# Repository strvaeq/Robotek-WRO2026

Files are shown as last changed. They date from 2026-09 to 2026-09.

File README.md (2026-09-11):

# Renkay - WRO 2026 Future EngineersrobotekPeru Flag

<p align="center">
  Banner Renkay
</p>





**Welcome! 🐨✨**

We are Renkay, a team of three students participating at the 2026 World Robot Olympiad! This GitHub repository contains the documentation, code, and full development journey of our autonomous vehicle, designed and built to compete in the Future Engineers Challenge.

<br>

> [!NOTE]
> 🤔 Why is our team named *Renkay*?<br><br>
> The name *Renkay* is inspired by three words that define our team: resilience, minka, and wiñay. "**Resilience**" represents our determination to never give up; "**minka**", an ancestral tradition of working together for a common purpose, reflects our belief that the best ideas are built through collaboration; and wiñay, which means "to grow", symbolizes our commitment to continuous learning and improvement. Together, these words represent who we are as a team, and guide every step of our robotics journey.

<br>

---

# 📮 Table of Contents
1. [About the Competition](about-the-competition)
   + [World Robot Olympiad (WRO)](world-robotic-olympiad-(wro))
   + [Future Engineers Category](future-engineers-category)
   + [Challenges Overview](challenges-overview)
2. [Repository Structure](repository-structure)
3. [Meet the Team!](meet-the-team)
4. [Vehicle Overview](vehicle-overview)
   + [General Description of the Car](#general-description-of-the-car)
   + [Versions of the Car](#versions-of-the-car)
     
5. [System Setup](system-setup)
   + [Operating Environment Overview](#operating-environment-overview)
   + [Robot Operating System (ROS)](#robot-operating-system-ros-)
   + [Ubuntu](#ubuntu-)
   + [Raspberry Pi](#raspberry-pi-)
     
6. [Mobility Management](mobility-management)
   + [Steering System - Ackermann](#steering-system--ackermann)
   + [Motor and Drivetrain](#motor-and-drivetrain)
   + [3D Pieces](#3d-pieces)
   
7. [Power & Sense Management](#power--sense-management)
   + [Power Source](#power-source)
   + [Sensors Integration](#sensors-integration)
   + [BOM (Bill of Materials)](#bom-bill-of-materials)
   + [Wiring Diagram](#wiring-diagram)

8. [Obstacle Management](obstacle-management)
   + [Control Node Structure](#control-node-structure)
   + [Open Challenge](#open-challenge)
   + [Obstacle Challenge](#obstacle-challenge)
     
9. [Assembly Instructions](#7-assembly-instructions)
10. [Performance Videos](#8-performance-videos)

---

## 1. About the Competition
### **<ins>World Robot Olympiad (WRO)</ins>**
The **World Robot Olympiad (WRO)** is a global robotics competition which brings together students to develop their creativity, engineering, and problem-solving skills. The competition offers four categories with different challenges.

### **<ins>Future Engineers Category</ins>**
We participate in the **Future Engineers category**, designed for students aged 14–22. In this category, teams design and build an autonomous vehicle using freely chosen hardware and software. It focuses on autonomous driving, requiring the vehicle to navigate a track and respond to changing conditions.

### **<ins>Challenges Overview</ins>**
| 🔓 Open Challenge | 🚨 Obstacle Challenge |
|---|---|
| In the **Open Challenge**, the vehicle must autonomously navigate the track and complete three laps. The track layout and driving direction can change between rounds, and the vehicle should adapt to different configurations. | In the **Obstacle Challenge**, the vehicle must complete three laps and detects the obstacles placed on the track. After completing it, the vehicle must perform a parallel parking maneuver. |
| Open Challenge | Obstacle Challenge

## 2. Repository Structure

| Folder | Content |
|---|---|
| [`t-photos`](t-photos) | Team photos (official one and funny one) |
| [`v-photos`](v-photos) | Photos of our vehicle (from every side, from top and bottom) |
| [`videos`](videos) | Demonstration video links of the robot in the challenges |
| [`schemes`](schemes) | Wiring diagram with pins and electronic components |
| [`src`](src) | Code of the robotic vehicle system |
| [`models`](models) | 3D printed parts and other chassis pieces |
| [`other`](other) | Extra documentation |

## 3. Meet the Team!

<table width="100%">
  <tr>
    <td width="75%" style="padding: 20px;">
      <h3><strong>Isabella Gonzales 🌟</strong></h3>
      <b>🔧 Role: </b>Team Member<br>
      <b>💬 About me:</b> Hello! My name is Isabella, I'm 17 years old, and I love robotics. I founded Robotek Perú, a club where students can learn robotics and join competitions, and this is my second time at the WRO. My favorite hobbies are singing with my choir, practicing taekwondo, and art.<br>
      <b>🌐 Contact:</b> isabellamilagros842@gmail.com
    </td>
    <td align="center" width="25%" style="padding: 20px;">
      
    </td>
  </tr>

  <tr>
    <td width="75%" style="padding: 20px;">
      <h3><strong>Rodrigo Osorio 🦙</strong></h3>
      <b>🔧 Role: </b>Team Member<br>
      <b>💬 About me:</b> Hi. I'm Rodrigo, a 16-year-old teenager passionate about many kinds of knowledge across a wide variety of fields. This is my third time taking part of the World Robot Olympiad however, in the past I'd taken part of Robo Mission: Junior through the 2024 and 2025 seasons. Besides robotics, I'm thrilled about humanities, specially philosophy, a field where curiosity can be flow naturally. I'm excited to take part in this year's WRO season!!<br>
      <b>🌐 Contact:</b> rod10peru@gmail.com
    </td>
    <td align="center" width="25%" style="padding: 20px;">
      
    </td>
  </tr>

  <tr>
    <td width="75%" style="padding: 20px;">
      <h3><strong>Valeria Hurtado 🎷🐛</strong></h3>
      <b>🔧 Role: </b>Team Member<br>
      <b>💬 About me:</b> Hellooo! My name is Valeria and I’m 17 years old. I’m curious about science, technology, and how things work, which is what got me into robotics. This is my first time participating in the WRO, and I’m excited to figure things out along the way. Outside robotics, I enjoy baking, cycling, and designing things on Canva.<br>
      <b>🌐 Contact:</b> valeria.hurtado.delarosa@outlook.com
    </td>
    <td align="center" width="25%" style="padding: 20px;">
      
    </td>
  </tr>

  <tr>
    <td width="75%" style="padding: 20px;">
      <h3><strong>Anthony Valladolid 🤓</strong></h3>
      <b>🔧 Role: </b>Coach<br>
      <b>💬 About me:</b> Hi, I am Anthony Valladolid, a Mechatronics Engineering graduate from Pontificia Universidad Católica del Perú, passionate about developing and researching emerging technologies. My main areas of interest are embedded systems, robotics, and applied artificial intelligence.<br>
      <b>🌐 Contact:</b> anthony.valladolid@pucp.edu.pe
    </td>
    <td align="center" width="25%" style="padding: 20px;">
      
    </td>
  </tr>
</table>

## 4. Vehicle Overview
This is our car named **Sami**, it is the result of multiple versions and modifications since 2024. We have been studying, learning and testing different methods to improve our car. It has been an interesting and challenging journey in robotics, but every effort was worth it!

<p align="center">
  

</p>

### **<ins>General Description of the Car</ins>**
Our autonomous vehicle is built to take on both the Open and Obstacle Challenges at the Future Engineers competition. Running on Ubuntu with ROS, it can process information and make decisions in real time. The car uses an Ackermann steering system and a custom-built chassis to move smoothly through turns and straight paths. A LiDAR sensor helps it detect the field walls, while the camera identifies traffic signs and obstacles. With this setup, the car can adapt its route, count laps, and complete the course efficiently.
<br>

| Front | Left | Right |
| :--: | :--: | :--: |
|  |  |   |

| Back  | Top  | Bottom |
| :--: | :--: |:--: |
|  |  |   | 
> [!NOTE]
> 📸 Visit our [`v-photos`](https://github.com/vania020/wro2025-robotek/tree/main/v-photos) folder for more detailed photos of the car

### **<ins>Versions of the Car</ins>**
Our vehicle has gone through **10 versions** (and since we are always improving, there are still more to come). It all started with a cardboard prototype, then moved on to acrylic and metal chassis designs, and later, we made personalized adjustments to a HiWonder kit. Along the way, we also experimented with different wheel designs, repositioned components, tested sensors like LiDAR, and finally adopted a new operating environment with ROS and Ubuntu.

<table>  
  <tr>
    <th width="10%">Version</th>
    <th width="40%">Car Photo</th>
    <th width="50%">Description</th>
  </tr>
  
  <!-- Version 1 -->
  <tr>
    <td align="center"><i>Version N°1</i></td>
    <td align="center">
      
    </td>
    <td>
      We built a cardboard prototype to test and understand the Ackermann steering system and wheel movement. This served as a reference to learn about the placement of components and systems.<br><br>
      <a href="v-photos/vehicle-versions/README.md#version-1">➡️ See more photos 🚗</a>
    </td>
  </tr>

  <!-- Version 2 -->
  <tr>
    <td align="center"><i>Version N°2</i></td>
    <td align="center">
    </td>
    <td>
      <br>We cut and incorporated an acrylic chassis and designed/3D-printed housing pieces for the camera, Ackermann system, and other components. The Ackermann used a stepper motor, and to perceive its surroundings, the car relied on infrared sensors and a webcam. 
      <br><br>The main controllers were a Raspberry Pi 4 and an Arduino Nano, powered by a power bank and lithium batteries. The car’s movement was driven by a single motor.<br><br> 
      <a href="v-photos/vehicle-versions/README.md#version-2">➡️ See more photos 🚗</a><br><br>
    </td>
  </tr>

  <!-- Version 3 -->
  <tr>
    <td align="center"><i>Version N°3</i></td>
    <td align="center">
    </td>
    <td>
      <br> We replaced the power bank with a smaller one, adjusted component placement into a two-level car system, and installed new wheels. Lithium batteries were replaced with higher-current ones, and the infrared sensors were moved to the front, so the vehicle could make more precise turns.<br><br>
      <a href="v-photos/vehicle-versions/README.md#version-3">➡️ See more photos 🚗</a><br><br>
    </td>
  </tr>

  <!-- Version 4 -->
  <tr>
    <td align="center"><i>Version N°4</i></td>
    <td align="center">
    </td>
    <td>
    <br> We upgraded the chassis to a modified HiWonder Kit and replaced the infrared sensors with a LiDAR for more accurate obstacle detection. The webcam was also switched to a monocular camera. The original car motor was replaced by two encoder motors, adapted with gears to drive a single wheel in compliance with competition guidelines.<br><br>

For the Ackermann steering, we replaced the stepper motor with a servomotor. On top of that, we moved away from the Arduino Nano and began implementing the ROS framework.<br><br>
<a href="v-photos/vehicle-versions/README.md#version-4">➡️ See more photos 🚗</a><br><br>
    </td>
  </tr>

  <!-- Version 5 -->
  <tr>
    <td align="center"><i>Version N°5</i></td>
    <td align="center">
    </td>
    <td>
      <br>Our main improvement was the chassis. We joined the two bases by drilling them together and carefully organized the components with the Raspberry Pi inside. The LiDAR was placed on top so nothing would block its view, and we also completed and installed the camera housing.<br><br>
      <a href="v-photos/vehicle-versions/README.md#version-5">➡️ See more photos 🚗</a><br><br>
    </td>
  </tr>

  <!-- Version 6 -->
  <tr>
    <td align="center"><i>Version N°6</i></td>
    <td align="center">
    </td>
    <td>
      <br> Wheels were changed to adjust the car’s height so the Lidar could detect walls within the 10 cm range (previously it was too high and failed). The housing material was upgraded from PLA to polycarbonate for greater resistance, and the Open Challenge (autonomous 3 rounds driving) was completed.<br><br>
      <a href="v-photos/vehicle-versions/README.md#version-6">➡️ See more photos 🚗</a><br><br>
    </td>
  </tr>

  <!-- Version 7 -->
  <tr>
    <td align="center"><i>Version N°7</i></td>
    <td align="center">
    </td>
    <td>
      <br> Using our HiWonder kit as the base, we designed and cut a completely new, smaller chassis with personalized mounting holes for all components, new housing pieces were created, and the two-motor system was replaced by a single motor in a gear system.<br><br>
    We also moved from a two-level structure to a single-level layout, placing all the components on the same surface to give the Raspberry Pi better airflow and easier access. The car successfully detected and avoided the first traffic signs.<br><br>
      <a href="v-photos/vehicle-versions/README.md#version-7">➡️ See more photos 🚗</a><br><br>
    </td>
  </tr>

  <!-- Version 8 -->
  <tr>
    <td align="center"><i>Version N°8</i></td>
    <td align="center">
    </td>
    <td>
      <br> <b>Car dimensions:</b> 15 x 23 cm <br><br>
      We 3D-printed new, slimmer front wheels because the original ones stuck out too much from the chassis. A custom housing was also printed for the batteries, and most importantly, the Ackermann steering servo was mounted vertically to save space and allow for a wider turning angle.<br><br>
During previous testing, we realized the LiDAR was struggling to properly detect the walls of the field, so we 3D-printed and implemented a small angled mount to give it a slight tilt.<br><br>
      <a href="v-photos/vehicle-versions/README.md#version-8">➡️ See more photos 🚗</a><br><br>
    </td>
  </tr>

<!-- Version 9 -->
  <tr>
    <td align="center"><i>Version N°9</i></td>
    <td align="center">
    </td>
    <td>
      <br> <b>Car dimensions:</b> 15 x 20 cm <br><br>
In this version, the components were arranged more efficiently to save space. We added a custom housing for the batteries, placed the Pi5 controller on top, and mounted the Raspberry above it, creating a layered system.<br><br> 
A new chassis base was printed in MDF, and the Ackermann was moved slightly because, in the previous version, the rack was colliding with the servo. To improve traction, we added a groove to the wheels and printed small cylinders between them to prevent contact with the screws. With these adjustments, the robot managed to complete a lap in <b>20 seconds</b>.<br><br>
      <a href="v-photos/vehicle-versions/README.md#version-9">➡️ See more photos 🚗</a><br><br>
    </td>
  </tr>

  <!-- Version 10 -->
  <tr>
    <td align="center"><i>Version N°10</i></td>
    <td align="center">
    </td>
    <td>
      <br> <b>Car dimensions:</b> 15 x 18 x 16 cm <br><br> 
We removed the LiDAR housing because, after testing the robot multiple times, we found that vision worked better without it. We also printed the rear wheels, so now all wheels are the same. We modified the gear system, which allowed the robot to complete the 3 laps faster. It now takes less than 10 seconds to complete an entire lap, and it manages to complete the 3 laps in 28 seconds. The small and big gears were interchanged so that the big gear is directly attached to the motor shaft
<br><br>
  <a href="v-photos/vehicle-versions/README.md#version-10">➡️ See more photos 🚗</a><br><br>
    </td>
  </tr>

  <!-- Version 11 -->
  <tr>
    <td align="center"><i>Version N°11</i></td>
    <td align="center">
    </td>
    <td>
      <br> <b>Car dimensions:</b> N x N x N cm <br><br> 
We noticed that the room lights were affecting our color detection, so we added a 16-LED WS2812 RGB ring light (5V) to keep the lighting consistent. We also moved the LiDAR again. We printed a new housing and placed it at the front, right under the chassis, an adjustment that significantly improved wall detection.
Finally, we replaced the old L298N motor driver with a TB6612FNG. This made a big difference because we can now control the speed more smoothly, starting at around 35%, and we have much better control when reversing and stopping.
<br><br>
  <a href="v-photos/vehicle-versions/README.md#version-10">➡️ See more photos 🚗</a><br><br>
    </td>
  </tr>
  
</table>

<br>

> [!NOTE]
> 🌱 Visit our [`vehicle-versions`](v-photos/vehicle-versions/README.md) folder to see photos and videos of our car evolution.

<br>

## 5. System Setup
### **<ins>Operating Environment Overview</ins>**
The operating environment of our robotic car is designed as a structure that connects hardware, software, and middleware into a single functional system, shown in the diagram below:

<p align="center">
  
</p>

### **<ins>Robot Operating System (ROS)</ins>** ROS
ROS is a framework that connects a robot’s software and hardware, making sensors, motors, and programs work together so the robot can perform tasks smoothly. For this project, we use ROS 2 Jazzy, one of the latest versions of ROS 2. You can find the documentation here:  [ROS 2 Documentation: Jazzy](https://docs.ros.org/en/jazzy/index.html)<br>

Without ROS, everything would have to be written in one long, complicated program that’s hard to manage. We can now divide the system into smaller parts, or nodes, that each do one job, making the system easier to build, fix, and expand.<br>

<p align="center">
  Nodes
</p>

> This is an official animation to better understand how nodes work. Each node does one clear job, like moving wheels or reading sensors, and they talk to each other using topics, services, actions, or parameters.
>  In practice, this is the process:
> 1. Sensors send data to ROS 2 by publishing it on topics.
> 2. Other nodes listen to that data, process it, and decide what the car should do.
> 3. Finally, a controller node sends commands, making the car move accordingly.

<br>

*<ins>Why we use ROS?</ins>*<br>

<table>
  <tr>
    <td><b>Sensor & Actuator Integration</b></td>
    <td>
      ROS connects all sensors and actuators in one system, ensuring seamless coordination. 
      This gives our autonomous car continuous information about its surroundings 
      and optimizes overall performance.
    </td>
  </tr>
  <tr>
    <td><b>Environmental Perception with LiDAR</b></td>
    <td>
      Most manufacturers of advanced sensors, such as LiDARs, provide an official package to use their hardware with ROS. In the case of the DTOF STL-19P, the manufacturer provides a package that automatically publishes the LiDAR data so it can be processed afterward.
    </td>
  </tr>
  <tr>
    <td><b>Support with Python</b></td>
    <td>
      ROS is fully compatible with Python, which allows for versatile and high-level code development. In addition, being open-source, it has a large community that provides support and assistance for robot development.
    </td>
  </tr>
  <tr>
    <td><b>Debugging & Simulation</b></td>
    <td>
      ROS includes tools to quickly debug the content published on topics. It also provides tools such as RViz, which allows real-time data visualization, and Gazebo, which enables running simulations.
    </td>
  </tr>
  <tr>
    <td><b>Efficient Simulation & Debugging</b></td>
    <td>
      Virtual environments like 
      <a href="https://gazebosim.org/home">Gazebo</a> let us fine-tune parameters before implementation. 
      Tools like 
      <a href="https://docs.ros.org/en/humble/Tutorials/Intermediate/RViz/RViz-User-Guide/RViz-User-Guide.html">RViz</a> 
      allow real-time visualization of sensor data and car status, making debugging much easier.
    </td>
  </tr>
</table>

<br>

### **<ins>Ubuntu</ins>** UBUNTU
Ubuntu is a popular, free, open-source operating system based on Linux. It is known for being reliable, flexible, and widely used in both research and industry. In our project, we use Ubuntu 24.04 as the **foundation that runs on the Raspberry Pi**.<br>

Ubuntu manages the Raspberry Pi’s resources efficiently, ensuring it runs correctly. It provides drivers and compatibility for sensors and external hardware, making integration easier. Ubuntu also allows us to install and run ROS 2 Jazzy and gives us access to important libraries and tools that simplify tasks such as sensor communication and system development.<br>

We use Ubuntu because of its stability and compatibility with ROS 2 Jazzy. Since ROS 2 packages are officially distributed for Ubuntu, using this operating system guarantees that we can easily install and manage the software needed for our car.
<br><br>

### **<ins>Raspberry Pi</ins>** Raspberry
The Raspberry Pi is a small computer that works as the brain of our car. It is powerful enough to run Ubuntu, ROS 2, and our algorithms in real time. In our project, we use the Raspberry Pi 5, which you can find here: [Raspberry Pi 5](https://www.raspberrypi.com/products/raspberry-pi-5/)<br>

**👉 Set up and configuration**<br>

With the [Raspberry Pi Imager](https://www.raspberrypi.com/software/), we flash Ubuntu 24.04 into the microSD card of the Raspberry. After that, we configure the basics like Wi-Fi, SSH for remote access, and hostname. And finally, we install ROS 2 Jazzy by following these steps: [Installation Ubuntu (deb packages)](https://www.google.com/url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)

| Step 1 | Step 2 | Step 3 | Step 4 |
| :--: | :--: | :--: |  :--: |
|  |  |  |  |

<br>

## 6. Mobility Management  

### <ins>**Steering System – Ackermann**</ins>

<p align="center">
  Ackermann
</p>

Our autonomous car uses an Ackermann steering system, controlled by a **15 kg·cm digital servo**, which provides precise and stable control for navigation and turns.  

The Ackermann steering geometry is designed to reduce tire slip by ensuring that all wheels align as radii of circles that share a common center when the car is turning. This configuration keeps the rear wheels fixed and places the center of rotation along a line extended from the rear axle. To achieve this geometry, the inside front wheel turns at a greater angle than the outside front wheel, allowing smoother and more efficient cornering.

---

### **Our own modifications ⚒️**

In the first versions of the car, we implemented the Ackermann steering system using a custom mechanism. We designed and 3D printed a gear connected to a stepper motor, along with a rack, which is a stick with grooves that fit into the gear teeth. When the motor rotated the gear, the rack would move, which in turn rotated the wheels.  

<p align="center">
  
  
</p>

One of the challenges we faced was the 3D printing process itself. Printing small details such as gear teeth was difficult and often imprecise, which caused problems in the initial prototypes. To solve this, we made the gear teeth larger, and while this worked mechanically, the final design ended up taking too much space inside the chassis.

For this reason, we decided to switch to the system we currently use, which is part of the **HiWonder kit**, adapted to fit in our chassis base. Instead of gears, it uses a system of linkages connected by screws and supported by bearings. These linkages move and transfer the motion to the wheels, achieving the Ackermann steering effect in a more compact way.

<p align="center">
  
</p>

> [!WARNING]
> At first, the Ackermann of the HiWonder kit worked fine — the car could turn and even get through some obstacles. But after a lot of testing, we noticed that whenever the car turned left, the Ackermann didn’t rotate as much as it did when turning right. This made obstacle avoidance harder, especially in the field corners, so we knew we had to make adjustments.

We realized that the servo needed to be repositioned. First, it was placed horizontally under the Ackermann linkages. We brainstormed how to make it more efficient and changed the position of the servomotor, mounting it vertically with the accessory facing downward under the chassis. This way, the linkages could move freely with more angles, and we also freed up extra space for the other components. This new placement also allowed us to reduce the length of the chassis.  

<table>  
  <tr>
    <th width="30%">Initial position</th>
    <th width="30%">Idea</th>
    <th width="30%">Final Position</th>
  </tr>
  <tr>
    <td align="center">
      
    </td>
    <td align="center">
      
    </td>
    <td align="center">
      
    </td>
  </tr>
  <tr>
    <td align="center">Servo mounted horizontally (limited angles)</td>
    <td align="center">Servo repositioned vertically</td>
    <td align="center">Final placement with improved steering</td>
  </tr>
</table>

---

### <ins>**Motor and Drivetrain**</ins>

<p align="center">
  
</p>

The drivetrain of our autonomous car is powered by a **25 mm metal gear DC motor**, chosen for its compact size and high torque. The motor is mounted on the chassis and directly connected to the rear axle through a system of gears, ensuring efficient transfer of power to the wheels.  

Our drivetrain includes a gear system:  
- The large gear is mounted on the motor shaft.  
- This large gear drives a smaller gear connected to the rear axle.  
- The result is an increase in the speed of the wheels.

<p align="center">
  
</p>

During assembly, we noticed a gap between the metal chassis part and the axle supports. This caused instability in the drivetrain. To fix it, we designed custom 3D-printed cylindrical spacers that fill the gap and keep the axle firmly in place. This simple solution reduces vibrations, prevents misalignment, and ensures smoother transmission of power from the motor to the wheels.

<p align="center">
  
</p>

#### **Motor Driver Upgrade & Mobility Improvements**
For this year's vehicle, we implemented a critical upgrade to our motor driver to resolve severe mobility issues. In our previous version, when the car's speed was reduced to 50% or lower, it would stop completely. The motor lacked the necessary force to overcome ground friction, a problem worsened by the overall weight of the car. 

By changing the driver, we have achieved a significant improvement in mobility management:
- **Low-Speed Efficiency:** The car now operates smoothly and maintains torque from as low as 35% speed without stalling.
- **Multi-directional Movement:** The upgrade allows the vehicle to move in different directions effortlessly, finally giving us the ability to reverse reliably.
- **Precision Braking:** We can now brake and stop the vehicle with much higher accuracy.

#### **Speed Configuration**
Through rigorous testing, we established specific speed configurations to optimize our sensor's performance. For the **Open Challenge**, we decided to cap the maximum speed at **70%** instead of running at 100%. This controlled speed ensures that the LiDAR sensor has enough processing time to accurately detect walls, preventing crashes and maintaining a reliable trajectory throughout the laps.

---

### <ins>**3D Pieces**</ins>

This are the 3D model parts of our vehicle.  
Below, you will find a table with our 3D-printed parts and their descriptions.

<table align="center" width="100%" style="table-layout: fixed;">
  <thead>
    <tr>
      <th width="30%">Component</th>
      <th width="40%">Preview</th>
      <th width="30%">Folder</th>
    </tr>
  </thead>
  <tbody>
    <tr>
      <td align="center"><b>Vehicle Base</b></td>
      <td align="center">
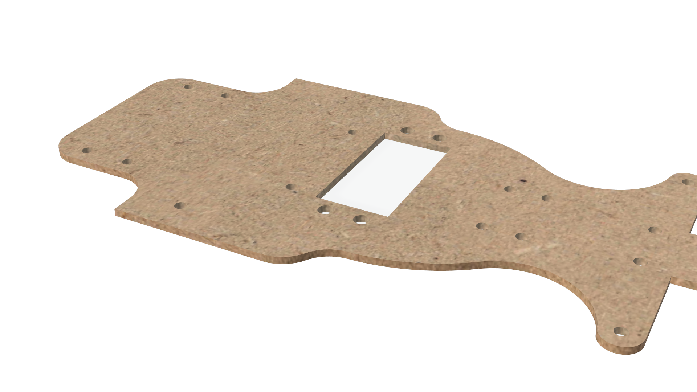
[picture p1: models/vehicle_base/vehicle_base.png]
        
      </td>
      <td align="center">
        <a href="models/vehicle_base/" target="_blank">View</a>
      </td>
    </tr>
    <tr>
      <td align="center"><b>Vehicle Wheels</b></td>
      <td align="center">
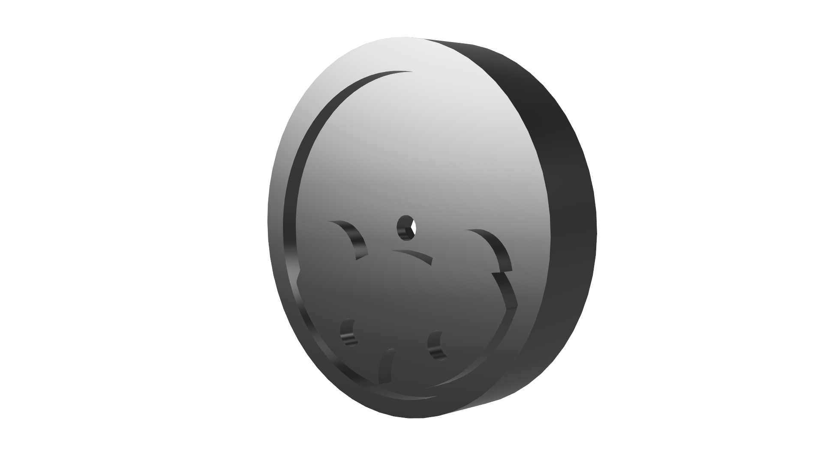
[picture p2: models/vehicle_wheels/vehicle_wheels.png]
        
      </td>
      <td align="center">
        <a href="models/vehicle_wheels/" target="_blank">View</a>
      </td>
    </tr>
    <tr>
      <td align="center"><b>Camera Housing</b></td>
      <td align="center">
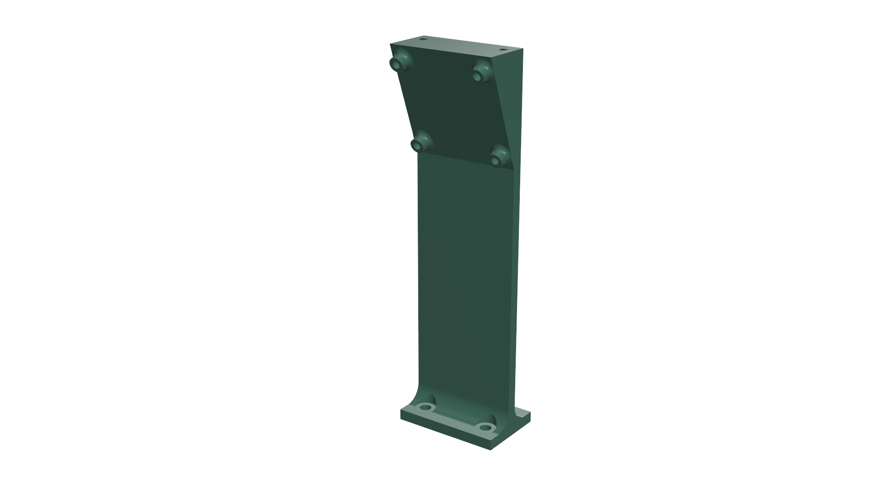
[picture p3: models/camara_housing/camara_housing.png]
        
      </td>
      <td align="center">
        <a href="models/camara_housing/" target="_blank">View</a>
      </td>
    </tr>
       <td align="center"><b>Raspberry Housing</b></td>
      <td align="center">
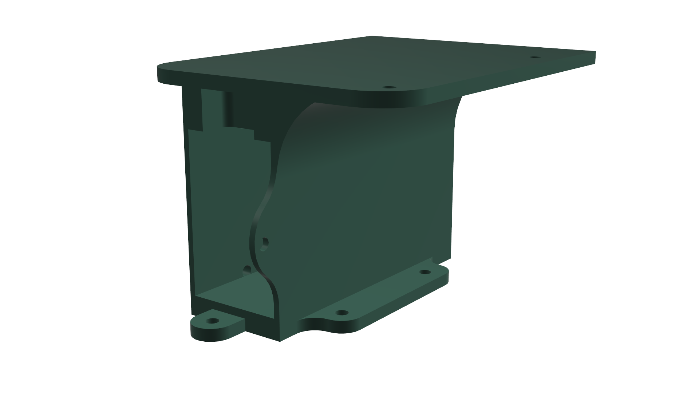
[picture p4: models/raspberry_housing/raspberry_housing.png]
        
      </td>
      <td align="center">
        <a href="models/raspberry_housing/" target="_blank">View</a>
      </td>
    </tr>
  <tr>
      <td align="center"><b>LiDar Housing</b></td>
      <td align="center">
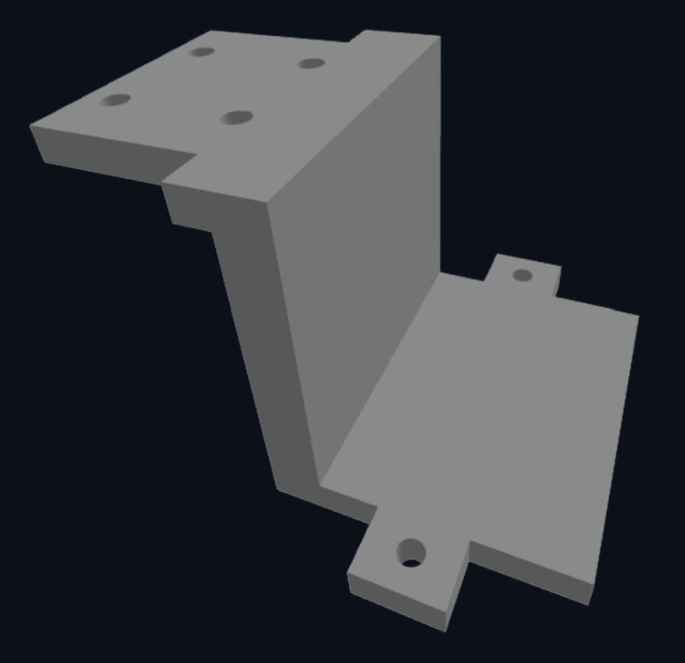
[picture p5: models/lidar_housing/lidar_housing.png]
        
      </td>
      <td align="center">
        <a href="models/lidar_housing/" target="_blank">View</a>
      </td>
    </tr>
  </tbody>
</table>

## 7. Power & Sense Management 

### <ins>**Power Source**</ins>

<p align="center">
  
</p>

Our autonomous car is powered by 7.4V Li-Po batteries (2000mAh, 20C). We chose Li-Po batteries because they provide a high energy density, meaning more power in a small and lightweight package. The battery provides two main energy lines: one for the electronics and another for the motor: <br>

1. **Electronics & Sensors**  
   The battery first connects to the **RRC Lite Controller**, which regulates the power down to a safe **5 V**.  
   From there, it distributes electricity to:  
   - **Raspberry Pi 5** → acts as the brain of the car, running ROS 2 and processing sensor data.  
   - **Digital servomotor** → controls the Ackermann steering system.  
   - **STL-19P TOF LiDAR & monocular camera** → provide vision and distance perception.  

2. **Drive Motor (via L298N Motor Driver)**  
   In parallel, the battery also powers the **L298N motor driver** directly with **7.4 V**.  
   This driver regulates how much current goes to the **25 mm metal DC motor**, which is responsible for moving the car forward.  

By splitting the power into two paths (one regulated for sensitive electronics and one direct for the motor), the system ensures stability. Motors usually demand sudden spikes of current, and separating their supply avoids crashes or interruptions in the Raspberry Pi and sensors.

### <ins>**Sensors Integration**</ins>
To perceive its environment and handle the Future Engineers challenges, the car uses a combination of:  

- **STL-19P TOF LiDAR**: provides 360° distance data.  
- **2DOF Monocular Camera**: detects colors and obstacles.
- **IMU (Built into the RRC Controller)**: tracks orientation, angular velocity, and acceleration.

Together, these sensors give the robot a better understanding of its environment by combining depth perception with visual input.

### <ins>**STL-19P TOF LiDAR**</ins>

<p align="center">
  
</p>

<br>

Unlike simpler sensors such as ultrasonic or infrared, which measure only in a single direction and have limited precision, the LiDAR sensor is capable of a **360° scanning** and provides precise distance measurements by using laser pulses. It helps the robot map its surroundings over a wide range, detect obstacles, and navigate more accurately in dynamic environments.

<br>

| Characteristic | Vaue |
|---|---|
| Ranging distance | 0.03 – 12 m |
| Size | 38.59 x 38.59 x 34.8 mm |
| Scanning Angle | 360° |
| Scanning Frequency | 5 – 13 Hz |
| Ranging Accuracy | ±45 mm |
| Ranging Frequency | 5000 Hz |

> [!IMPORTANT]
> **📍Placement:**
> For this version, we decided to lower the LiDAR In our previous design, a higher placement caused the sensor to occasionally look over the walls, missing the track boundaries or detecting noise outside the field. By lowering it, the LiDAR now aligns perfectly with the 10 cm high walls of the track. This guarantees a clear, reliable view of the limits and obstacles. All other components on the car were carefully arranged below this level to avoid blocking the LiDAR’s line of sight. <br><br>
  
### <ins>**2DOF Monocular Camera**</ins>

<p align = "center">
  
  </p>
<br>

The 2DOF Monocular Camera complements the LiDAR by adding visual perception. This allows the robot to recognize its environment beyond distance data, enabling future applications such as detecting the obstacles’ colors:

 + **Color detection**: Since graphical color detection is a core part of our  project, the camera can precisely identify various colors on the course. This allows our car to interact with the different traffic signs in the Obstacle challenge.
  + **Spatial awareness through data fusion**: When combining camera data with our sensor, the robot gains a richer understanding of its environment. The camera provides detailed visual context that leads to an adaptable navigation strategy.

> [!IMPORTANT]
> **📍Placement:**
> The camera is located in a special 3D mounting piece with a certain  inclination angle that points to the floor so it can better detect obstacles. At first it was placed at the front of the car but this location provided a limited vision and sticked out of the chassis lenght. See more detailed info of the housing piece in the [`3D Printed Parts`](#3d-printed-parts) section. <br><br> 
> 

### **<ins>BOM (Bill of Materials)</ins>**
| Component | Quantity | Description | Image |
|---|---|---|---|
| Raspberry Pi 5 | 1 | Main processing unit for running **ROS**. Acts as the main brain and the Host Controller of the system, capable of running operating systems and handling complex processing tasks. | Raspberry Pi 5 |
| RRC Lite Controller | 1 | Integrates: ROS expansion board, High-Frequency PID Control, Motor Closed-Loop Control, Servo Control and Feedback, IMU Data Acquisition, Power Status Monitoring, and a Power Switch. | Controller |
| STL-19P TOF Lidar | 1 | Provides precise, 360-degree distance measurements for real-time navigation and obstacle detection in dynamic environments. | Lidar |
| Lidar Adapter Board | 1 | Converts the LiDAR’s UART signals to USB for PC connection and data reading. | Adapter |
| 15 kg.cm Digital Servo | 1 | Provides accurate steering control. | Servo |
| 25MM Metal Gear Motor | 1 | Core drive motor for powering the wheels with torque and speed. | Motor |
| Suitcase Wheel Protector | 4 | Ensures 3d-printed wheels stability and grip on the floor. | tire |
| Monocular Camera | 1 | A camera used for capturing images and videos, can be used for computer vision or live streaming. | Camera |
| TB6612FNGm Motor Driver | 1 | Controls motor direction and speed from the Raspberry Pi. | Motor Driver |
| Jumper Cables | 4–8 | Electrical connections between the motor driver and Pi. | Jumper Cables |
| USB-USB Cable | 1 | A cable to connect the Raspberry Pi to the camera, Lidar, and Controller. | USB Cable |
| Li-Po Battery 7.4 V 5000mAh 20C | 1 | A lithium polymer battery that provides portable, high-density power. | Battery |
| 16-LED WS2812 RGB pixel ring light | 1 | A circular light module which make much easier to clearly see and distinguish the colors of the blocks. | Battery |

### <ins>**Wiring Diagram**<ins>

The following visual wiring diagram illustrates the **physical connections** between the modules (Raspberry Pi, LiDAR, camera, motor, etc.) using **realistic component images**. It helps visualize the system layout and understand **how components are arranged and linked** in the robot.  

<p align="center">
  
</p>

#### **1. Raspberry Pi 5 Connections**
The Raspberry Pi 5 works as the brain of the car. Its USB ports connect the main sensors and the controller:

+ Camera → provides visual input for detecting traffic signs and colored obstacles.
+ LiDAR → provides distance and wall detection for navigation.
+ RRC Lite Controller → interfaces with the digital servomotor and forwards control signals to the motor driver.

<p align="center">
  
</p>

#### **2. RRC Lite Controller**
The RRC Lite Controller acts as a bridge between the Raspberry Pi and the actuators. It regulates incoming power from the Li-Po battery (down to a safe 5 V) and distributes it to:  
- The **Raspberry Pi 5**  
- The **digital servomotor** for Ackermann steering  

It also handles communication with the motor driver to send PWM control signals.

---

#### **3. Motor Driver and DC Motor**
The **L298N Motor Driver** is powered directly by the **7.4 V Li-Po battery**.  
- It regulates both the **speed** and **direction** of the **25 mm metal gear DC motor**.  
- The motor then powers the rear axle through a gear reduction system, increasing torque for smoother acceleration.  

---

#### **4. Power Source**
The **7.4 V Li-Po battery** supplies energy to the entire system, split into two paths:  
- **Direct line (7.4 V):** powers the L298N motor driver and DC motor.  
- **Regulated line (via RRC Lite Controller):** delivers 5 V to the Raspberry Pi, servomotor, and sensors.  

<br>

This is also a diagram that shows the **electrical wiring** and pin-level connections between all components — including power lines, GPIOs, and communication ports. It focuses on **signal paths and voltage levels** rather than physical appearance.  

<p align="center">
  
</p>

> [!NOTE]
> Visit our [`schemes`](https://github.com/vania020/wro2025-robotek/tree/main/schemes) folder to access all of our diagrams and schemes 🔑🚗

## 6. Obstacle Management 

### <ins>**Control Node Structure**</ins>

Since we use ROS 2 as the middleware that connects all the components of our autonomous vehicle, there isn't a single code that runs either the Open Challenge or the Obstacle Challenge. Instead, the system is built as a collection of independent but interconnected ROS 2 nodes, each performing a specific function such as reading the camera, processing LiDAR data, or controlling the motors. These nodes communicate constantly through topics and messages, allowing the car to behave as a cohesive, intelligent system.

This table better explains our ROS topics and messages:

| **Node** | **Role** | **Topic** | **Message Type** | **What It Transmits** |
| --- | --- | --- | --- | --- |
| **LiDAR Node** | Publisher | `/scan` | `sensor_msgs/LaserScan` | It sends 360° distance readings from the LiDAR; each value represents how far an obstacle is at a given angle. |
| **Camera Node** | Publisher | `/obstaculos` | `std_msgs/String` | It publishes the detected obstacle color in a text form: (`rojo`, `verde`, or `ninguno`), which defines how the main controller adjusts the steering setpoint. |
| **AckerLidar Node** *(Main Controller)* | Central Controller | `/motor_vel`, `/positionServo` | `std_msgs/Float32`, `ros_robot_controller_msgs/SetAckerServoState` | `/motor_vel`: Motor duty cycle (speed %). `/positionServo`: Steering position (PWM in µs) for Ackermann control. |
| **Motor Node** | Subscriber | `/motor_vel` | `std_msgs/Float32` | Receives motor velocity commands from the main controller and translates them into PWM signals for the DC motor driver (L298N). |
| **Raspberry Pi 5 Controller Node** | Subscriber | `/positionServo` | `ros_robot_controller_msgs/SetAckerServoState` | Executes servo position commands and moves the front wheels to reach the target angle. |
| **RRC Controller Button** | Publisher | `/button` | `ros_robot_controller_msgs/ButtonState` | Sends an activation signal when the onboard button is pressed, starting the robot’s control loop. |

### **What is a Message type?**

A **message type** is like a template that defines **what kind of data** is sent through a *topic*. For example, ROS already includes many built-in types, such as:

* `std_msgs/String` → used to send text.
* `std_msgs/Float32` → used to send a decimal number.
* `sensor_msgs/LaserScan` → used to send LiDAR data (distance readings around 360°).
* `geometry_msgs/Twist` → used to send linear and angular velocities (very common in mobile robots).
* And you can also have **custom message types**, like the ones included in your own package `ros_robot_controller_msgs`.

### **Important clarifiactions**

* For simplicity, **some topic names were shortened** in the diagrams.

  * The real ROS topic `/ros_robot_controller/acker_servo/set_state` is represented as **`/positionServo`**.
  * The real ROS topic `/ros_robot_controller/button` is represented as **`/button`**.

* The button input `/ros_robot_controller/button` is processed internally by the main node and does not appear as a separate node because it doesn’t exchange messages with others.

* The naming convention was simplified only for documentation clarity; all logic and connections in the code remain unchanged.

* The **AckerLidar Node** acts as the core controller that links everything:
  it subscribes to LiDAR and camera data, processes the PID control, and publishes both the steering and velocity commands.

> [!NOTE]
> If you would like to see a detailed description and explanation of the code behind each node, please visit our [`src`](https://github.com/vania020/wro2025-robotek/tree/main/src) folder 🖥️🚗
> 

---

### <ins>**Open Challenge**</ins>

The **Open Challenge** is the first autonomous driving test. In this stage, the robot must complete three laps **without any external input** relying only on its onboard **LiDAR sensor**, **PID controller**, and **Ackermann steering system**. The goal is to keep the car centered between the inner and external walls of the challenge during the entire lap. To achieve that, the robot constantly measures two key distances: **D₁** → Distance from the car to the **left wall** and **D₂** → Distance from the car to the **right wall**

The **control goal** is defined by the equation:

> **D₁ - D₂ = 0**  
> *(Setpoint = 0 → car is centered)*

When this balance holds true, it means that both walls are equidistant, and the car is aligned in the center of the track.

<p align="center">
  
</p>

### **How It Works: LiDAR + Control Loop**

The LiDAR sensor scans the surrounding environment in real time, detecting obstacles and measuring the distances around the car. From these scans, two zones are analyzed, one on the **left** and one on the **right** to extract D₁ and D₂.

These values are sent to the **AckerLidarNode**, the main control node in charge of:
- Reading and processing LiDAR data  
- Computing the distance difference `error = D₁ - D₂`  
- Sending control signals to the **steering** and **motor** nodes

The logic is the following:  
1. If **D₁ > D₂**, the car is too close to the right wall → it turns slightly **left**.  
2. If **D₁ < D₂**, the car is too close to the left wall → it turns slightly **right**.  
3. If **D₁ = D₂**, the car is centered → it continues straight.

This process runs in a **PID feedback loop**, where:
- The **P (Proportional)** term corrects small deviations quickly.  
- The **I (Integral)** term reduces long-term bias (not always needed).  
- The **D (Derivative)** term prevents oscillations and overshoot.  

The result is a **smooth, stable trajectory** that keeps the car aligned throughout the race.

<div align="center">
  
</div>

### **Open Challenge Flowchart**

 

#### Step-by-Step Description

1. **Start Robot & Initialization**  
   ROS2 nodes are launched: the LiDAR begins scanning, and the control node initializes all parameters (PID gains, setpoint, motor topics).

2. **Continuous Loop**  
   The system enters a continuous loop (`while rclpy.ok()`), running dozens of times per second. Each cycle updates sensor readings and steering actions.

3. **LiDAR Scan Environment**  
   The sensor performs a 360° scan to detect the walls and extract points on both sides of the track.

4. **Extract Wall Distances (D₁, D₂)**  
   The algorithm filters the LiDAR data to isolate the left and right regions, computes the average distance for each, and updates D₁ and D₂.

5. **Compute Error (D₁ - D₂)**  
   The difference between these distances represents how “off-center” the car is from the ideal middle of the lane.

6. **PID Steering Adjustment**  
   The PID controller processes this error and outputs an angle correction, which is sent to the **servo motor** using an Ackermann steering model.

7. **Update Lap Counter**  
   The control node counts laps based on internal flags or distance traveled (depending on the implementation in the ROS2 package).

8. **3 Laps Completed → Stop Vehicle**  
   After completing three full laps, the system safely reduces speed and stops the motor node.

### **Nodes and Communication**

During the Open Challenge, three ROS2 nodes work together in real time:

| Node | Role | Description |
|---|---|---|
| **`AckerLidarNode`** |Main Control Node | Subscribes to LiDAR data, calculates the distance difference, runs the PID controller, and sends steering/motor commands. |
| **`MotorPWMNode`** | Motor Control | Receives speed values (`Float32`) and controls the DC motor through PWM signals, ensuring smooth acceleration. |
| **`SetAckerServoState`** | Steering Control | Adjusts the steering servo angle according to PID output, maintaining Ackermann kinematics. |

---

### <ins>**Obstacle Challenge**</ins>

<p align="center">
  
</p>

### **Obstacle Challenge Flowchart**

<p align="center">
  
</p>

<br><br>
## 7. Assembly Instructions 

### **Ackermann System**
+ To build the Ackermann system on the car, first screw the fixed parts that attach the system to the base.
+ Next, attach the two movable pieces that steer the wheels to the sides of the fixed part. Make sure these pieces can still rotate freely. Each of these pieces has two holes use the hole that is closer to the wheels.
+ Then, connect the wheel pieces with a linkage that has bearings on both ends. The bearings should be screwed into the other holes of the wheel pieces, forming a movable, half-rectangular structure.
+ Attach a second linkage, identical to the first but shorter, to one side of the system. This linkage connects to one of the holes on the wheel pieces, the same ones linked to the bearings of the first linkage. This shorter linkage will move the steering system and must be connected directly to the servo motor, which should be mounted vertically on the base.
+ Important: The servo’s output shaft and the side where the second linkage is attached should be on opposite sides.
Finally, attach the wheel hubs, the parts that hold the actual wheels, to the movable pieces via bearings. These bearings should allow the wheels to rotate freely.
 
### **Motor System**
+ Screw the motor mount, which is the piece that holds both the motor and its axle, onto the base. Then, screw the motor to this mount.
+ Insert the axle into the mount. The mount has two circular openings that the axle passes through. The axle should be supported by two bearings, which keep it centered, and two locking rings, which prevent side movement.
+ Once the axle is in place, connect the motor shaft and the axle using spacers, ensuring they do not collide with the motor screws.
 
### **Housings**
After both systems are assembled, install the housings on the top side of the base. Mount the camera, LiDAR, batteries, and Raspberry Pi according to the model layout:
+ The LiDAR housing goes at the front, ensuring its field of view is unobstructed.
+ The camera housing goes right behind the LiDAR housing, which it’s taller, so its view remains clear.
+ The battery and Raspberry Pi housings go behind them, forming a sort of ceiling above the servo motor that protrudes from the base.
 
### **Electronics**
Finally, install all electronic components, attaching them to their designated housings and connecting them according to the wiring diagram.

<br><br>
## 8. Performance Videos 

<div align="center">

| Challenge | YouTube Video |
|---|---|
|  | <a href="https://youtu.be/lE8SPT6_tL0?si=ECjmNy6-T6QCe0LI">Watch on YouTube 🎥</a> |
|  | <a href="https://youtu.be/DUVe36ZpR18?si=IGmmhTL5FZdeEi8m">Watch on YouTube 🎥</a> |

</div>

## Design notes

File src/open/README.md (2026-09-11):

<p align="center">
  
</p>

Autonomous robot that drives the track and stops after 3 laps, using a
cascaded **lidar + IMU** controller on ROS 2 (Raspberry Pi 5).

## How it works

Two loops that complement each other:

- **Outer loop (lidar, ~10 Hz):** reads the side walls and computes a target
  heading to keep the robot centered in the corridor.
- **Inner loop (IMU, ~50 Hz):** integrates the gyroscope to track the current
  heading and outputs the steering angle that chases that target. It is the
  only loop that writes to the servo.

The lidar decides *where* to go; the IMU decides *how* to hold the heading. At
each corner ±90° is added to the base heading and the inner loop performs the
turn on its own. Laps are counted from integrated yaw (4 corners of 90° =
360° = 1 lap).

State machine:

```
IDLE --(button)--> CALIBRATING --(4 s)--> STRAIGHT <--> TURNING --(3 laps)--> DONE
```

## Files

| File | Purpose |
|---|---|
| `config.py` | All tunable parameters (gains, thresholds, servo, motor). |
| `control.py` | Pure logic: inner/outer loops, corners, lap counting, servo mapping. |
| `motor_driver.py` | ROS node for the TB6612FNG motor driver. |
| `robot_node.py` | Main node: state machine tying both loops together. |

## Running

```bash
python3 motor_driver.py    # motor driver
python3 robot_node.py      # main controller
```

Press the controller button to calibrate and start.

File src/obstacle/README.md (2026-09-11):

<p align="center">
  
</p>

Autonomous robot that follows a wall, drives around red/green pillars, and
stops after 3 laps, using an IMU heading loop, LiDAR wall geometry and a
camera color detector on ROS 2 (Raspberry Pi 5).

## How it works

- **Camera:** detects the nearest red or green block. Color chooses which wall
  to follow — **red → right wall, green → left wall** — and adds a small
  heading nudge to steer around the block while it is close.
- **LiDAR (~10 Hz):** fits a line to two side beams (60° and 30°) to get the
  distance and angle to the followed wall, and detects corners (front wall
  close + open side).
- **IMU (~50 Hz):** integrates the gyroscope to track heading and outputs the
  steering angle that holds the target. It is the only loop that writes to the
  servo. At each corner ±90° is added to the base heading.

Laps are counted from integrated yaw (4 corners of 90° = 360° = 1 lap).

State machine:

```
IDLE --(button)--> CALIBRATING --(4 s)--> FOLLOWING <--> TURNING --(3 laps)--> DONE
```

## Files

| File | Purpose |
|---|---|
| `config.py` | All tunable parameters (gains, wall target, HSV ranges, corners). |
| `color_vision.py` | HSV red/green block detector (OpenCV). |
| `control.py` | Pure logic: heading loop, wall follow, block avoidance, corners, laps. |
| `robot_node.py` | Main node: state machine tying the three sensors together. |
| `motor_driver.py` | ROS node for the TB6612FNG motor driver (shared with the Open Challenge). |

## Running

```bash
python3 motor_driver.py    # motor driver
python3 robot_node.py      # main controller
```

Press the controller button to calibrate and start.

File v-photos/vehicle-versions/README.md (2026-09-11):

Renkay

<details>
  <summary>🚗 Version 1</summary>

| Version1_1 | Version1_2|
|---|---|
|  | Version1_4 |
| Version1_5 | Version1_6 |

</details>

<details>
  <summary>🚗 Version 2</summary>

|Version2_1 |Version2_2|
|---|---|
| Version2_3 |Version2_4|
|Version2_5 | Version2_6|

</details>

<details>
  <summary>🚗 Version 3</summary>

|Version_3 | Version3_1|
|---|---|
| <video src="https://github.com/user-attachments/assets/6eacc7fe-c0a3-41d3-8a91-9b308436cb5c" controls width="300"></video> | <video src="https://github.com/user-attachments/assets/b95e6bf3-f4a5-498e-a463-fc855877e273" controls width="300"></video> |

</details>

<details>
  <summary>🚗 Version 4</summary>

|Version4_2 |Version4_1 |
|---|---|
|Version4_3| Version4_4|
| Version4_5 | Version4_6 |

</details>

<details>
  <summary>🚗 Version 5</summary>

| Version5_1|Version5_2 |
|---|---|
|Version5_3| Version5_4|
| Version5_5| Version5_6|

</details>

<details>
  <summary>🚗 Version 6</summary>

| Version_6 | Version_6|
|---|---|
| <video src="https://github.com/user-attachments/assets/f36f642c-d2df-405a-8f7c-5bf95a052c07" controls width="300"></video> | <video src="https://github.com/user-attachments/assets/267cbbfe-3e4c-4b7d-ae23-0c0a9ceb5a3c" controls width="300"></video> |

</details>

<details>
  <summary>🚗 Version 7</summary>

| Version7_3|Version7_4|
|---|---|
| <video src="https://github.com/user-attachments/assets/7f9c4723-8aec-46f7-922d-036e9eb88da0" controls width="300"></video> | <video src="https://github.com/user-attachments/assets/6fb51656-d793-4519-9e96-b810b5ebbbea" controls width="300"></video> |

</details>

<details>
  <summary>🚗 Version 8</summary>

| Version8_1|Version8_2|
|---|---|
| Version8_3| Version8_4 |
|version8| ackermann |

</details>

<details>
  <summary>🚗 Version 9</summary>

|  ||
|---|---|
| <video src="https://github.com/user-attachments/assets/e9397982-21c5-499b-800a-85f2eb6be0a0" controls width="300"></video> | <video src="https://github.com/user-attachments/assets/c0ddc48a-6913-4427-ab60-49d417406f30" controls width="300"></video> |

</details>

<details>
  
  <summary>🚗 Version 10</summary>

|||
|---|---|
||  |

</details>

<details>
  <summary>🚗 Version 11</summary>

|  |  |
|---|---|
| <video width="1600" height="1200" alt="image" src="https://github.com/user-attachments/assets/61eeb26a-ec0f-41b2-82eb-45fa9eade09b" /> |  |

</details>

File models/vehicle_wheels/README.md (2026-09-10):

Renkay

LVehicle Wheels

This is our front wheel design. Although we use standard Hi-Wonder Kit wheels at the back, we noticed that the front wheels were sticking out of the chassis too much, making the robot wider. To solve this, we decided to 3D print custom wheels with a 6 mm diameter.

Initially, we used them without any rubber or friction border, but the car couldn’t move properly. Later, we added a wheel border to increase traction, and everything worked perfectly. To give the robot a unique look, we also integrated the Robotek logo (the koala) into the wheel design.

**Model Details**
- Format: `.stl`
- Material: PLA
- Layer height: 0.20 mm
- Infill: 25%
- Supports: Yes, for internal cavities

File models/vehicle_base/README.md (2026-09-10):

Renkay

Vehicle Base

This piece is the **main platform of our vehicle**. It supports all the main componentslike the the Raspberry Pi, LiDAR, and camera housings. It was **laser-cut from MDF**, which gives it a good balance between strength and lightness. The design includes **placed holes** for screwing in the electronic and mechanical parts.

For the fabrication process, we started by sketching the base on squared paper and then prototyping it on cardboard. We used acrylic to test the dimensions on our first models. After confirming the fit, we finalized the design in Fusion 360 and cut it in MDF for the final version. 

<br>

<p align = "center">
  
</p>

> [!NOTE]
> This was our previous chassis design. It consisted of a base and upper casing that were crafted from aluminum. The base was designed to mount the Raspberry Pi and support the weight of the vehicle’s systems. The upper casing, which houses the LiDAR sensor, was designed to ensure the sensor has an unobstructed view. Still, having the components packed wasn't efficient for immediate modifications, which is why we changed it.

**Model Details**
- Format: `.stl` (Fusion 360 export)
- Material: MDF
- Layer height: 0.2 mm (if 3D printed)
- Support: Not required

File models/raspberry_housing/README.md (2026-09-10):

Renkay

Raspberry Housing

We designed this structure as a **space-efficient housing** that could hold the **RRC Lite Controller** with the **Raspberry Pi 5**, our **7.4 V batteries**, and the **TB6612FNGm Motor Driver** at the back. The design integrates components vertically to reduce the length of the car.

**Design Highlights**
- Vertical design that saves horizontal space within the vehicle chassis.  
- Holds the Raspberry Pi and RRC Controller securely in stacked alignment.  
- Integrated compartment for battery placement underneath.
- Includes screw holes at the back for the motor driver. 

**Model Details**
- Format: `.stl`
- Material: PLA
- Layer height: 0.16 mm
- Infill: 20%
- Supports: Minimal (internal)

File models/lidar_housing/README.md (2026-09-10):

Renkay

<p align="center">
  LiDAR Housing
</p>

This part works as the mount for the LiDAR sensor. In this updated design, the sensor is positioned lower to significantly improve obstacle detection. The design includes screw holes that secure it firmly to both the vehicle chassis and the LiDAR itself, ensuring stability while the robot moves.

**Model Details**
- Format: `.stl`
- Material: PLA
- Layer height: 0.24 mm
- Infill: 25%
- Supports: Yes, for internal cavities

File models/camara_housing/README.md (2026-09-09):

<p align="center">
  
</p>

<p align="center">
  
</p>

This component holds our DOF camera. It ensures a correct viewing of the obstacles thanks to the inclination angle. The mount features screw holes and is designed to fit the front section of the robot chassis.

**Model Details**
- Format: `.stl`
- Material: PLA
- Layer height: 0.16 mm
- Infill: 25%
- Supports: Required (base only)

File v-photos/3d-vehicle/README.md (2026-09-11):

Renkay

| Front | Left | Right |
|:--:|:--:|:--:|
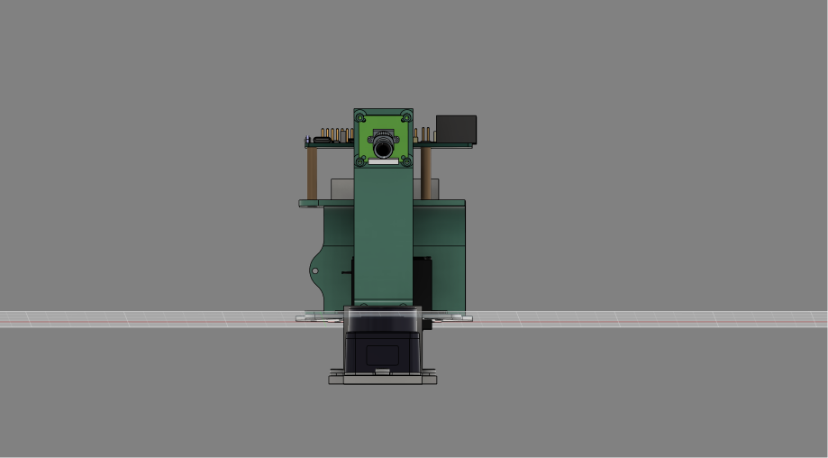
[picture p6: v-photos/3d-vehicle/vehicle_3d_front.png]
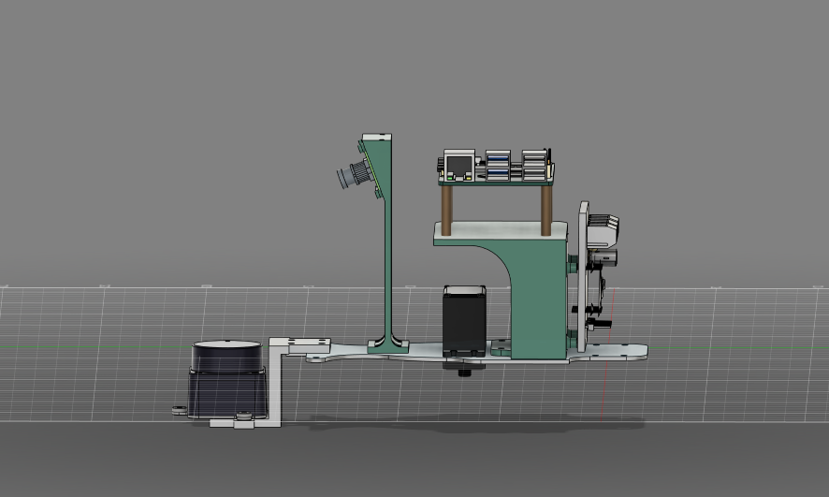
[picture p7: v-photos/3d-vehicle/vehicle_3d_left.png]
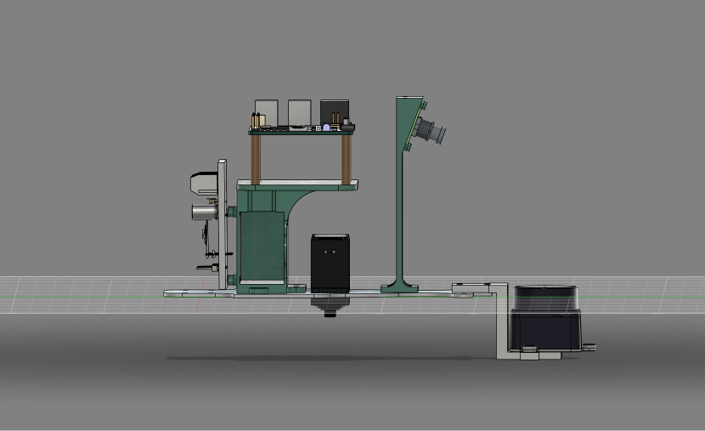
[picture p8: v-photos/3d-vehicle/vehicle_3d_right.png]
|  |  |  |

| Back | Top | Bottom |
|:--:|:--:|:--:|
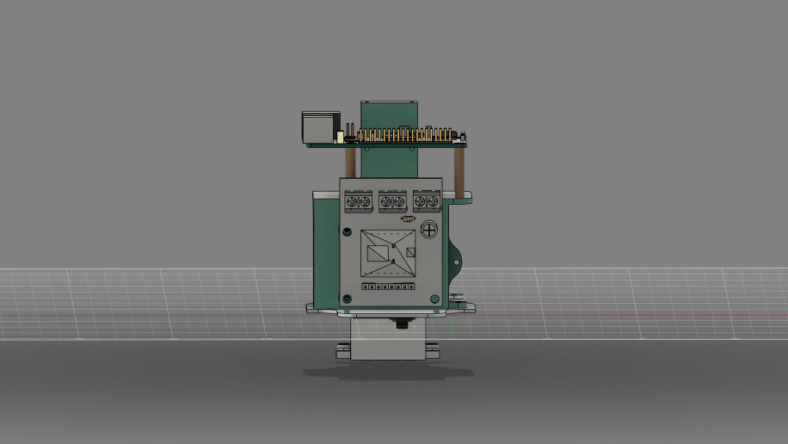
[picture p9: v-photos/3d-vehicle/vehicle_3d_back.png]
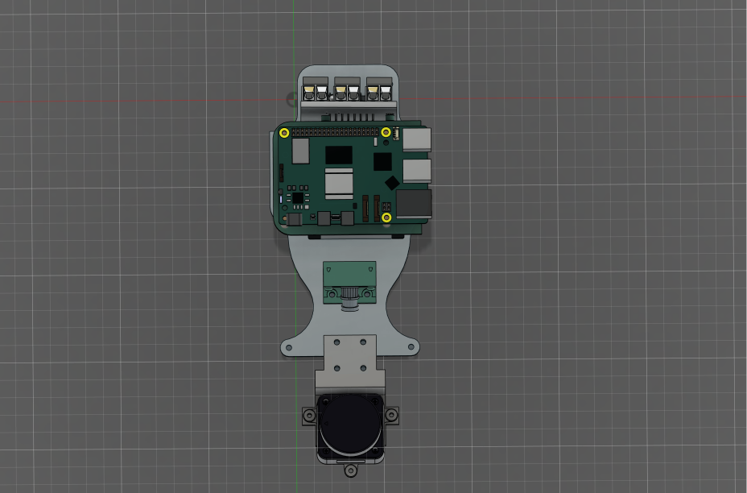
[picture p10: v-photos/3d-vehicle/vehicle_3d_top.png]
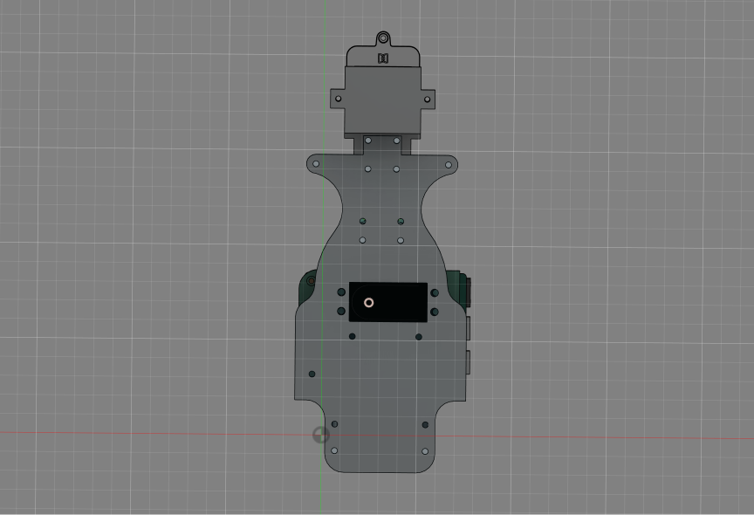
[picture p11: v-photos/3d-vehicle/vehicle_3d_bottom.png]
|  |  |  |

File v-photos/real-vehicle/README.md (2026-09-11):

Renkay

| Front | Left | Right |
|:--:|:--:|:--:|
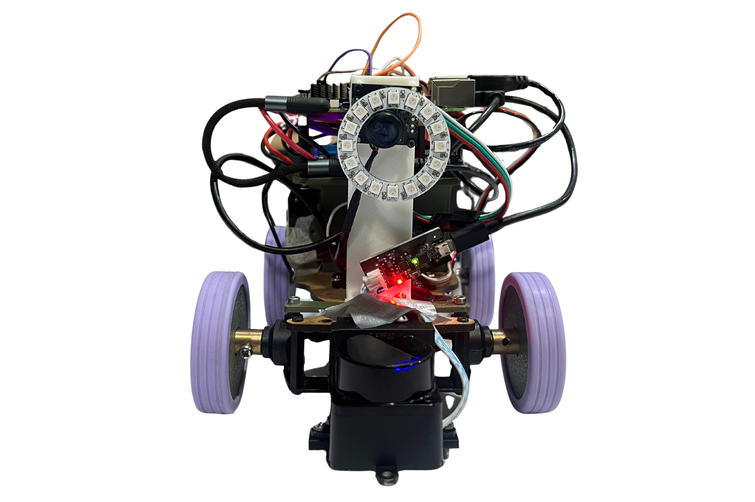
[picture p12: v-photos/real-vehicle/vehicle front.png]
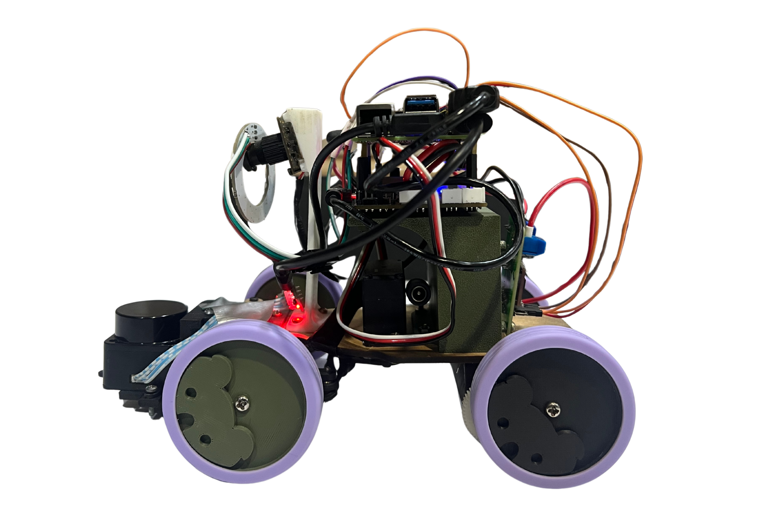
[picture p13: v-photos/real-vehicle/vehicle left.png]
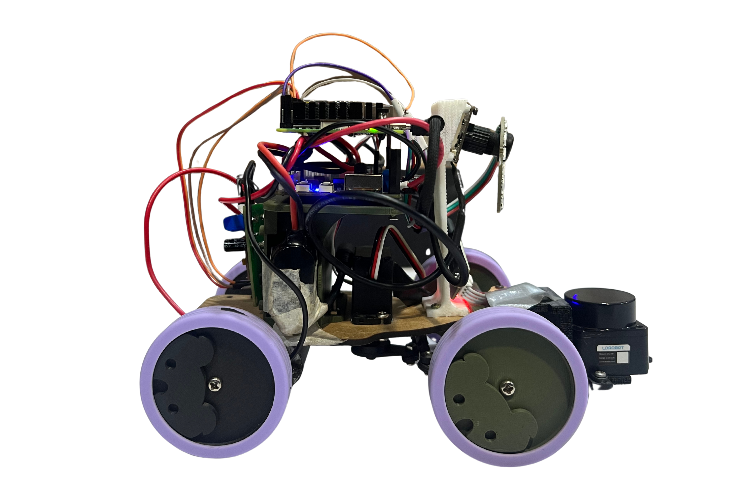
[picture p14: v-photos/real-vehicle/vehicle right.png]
|  |  |  |

| Back | Top | Bottom |
|:--:|:--:|:--:|
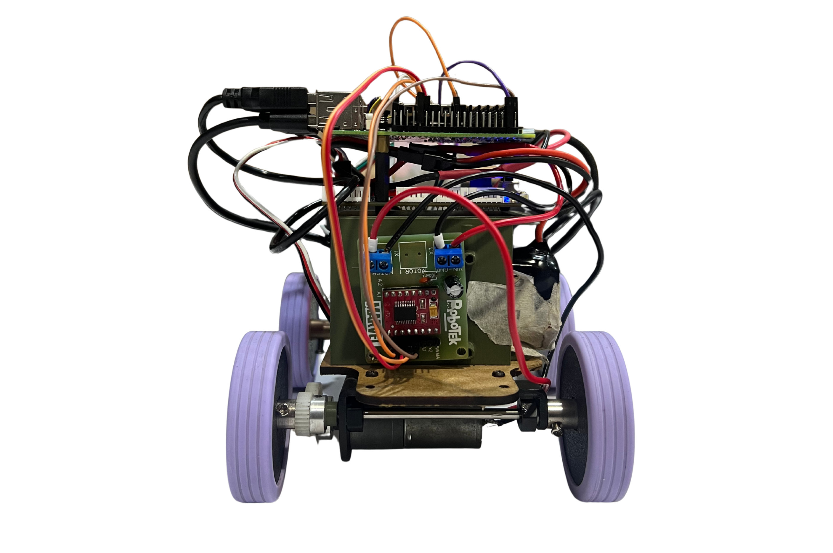
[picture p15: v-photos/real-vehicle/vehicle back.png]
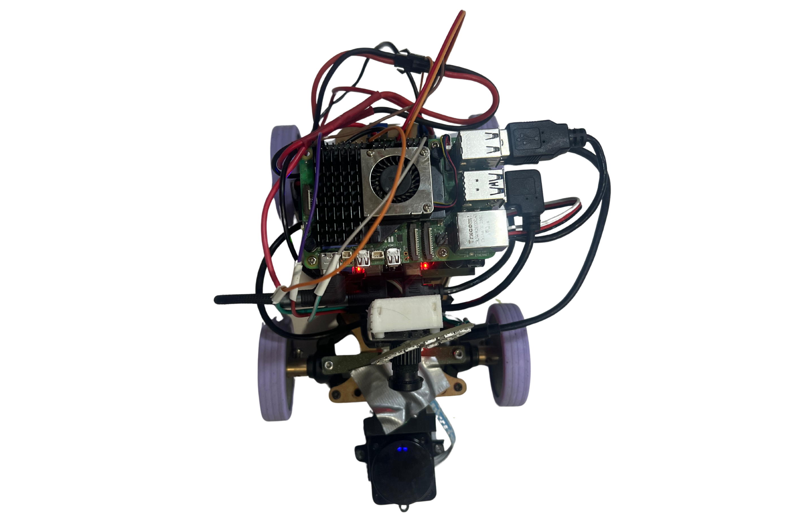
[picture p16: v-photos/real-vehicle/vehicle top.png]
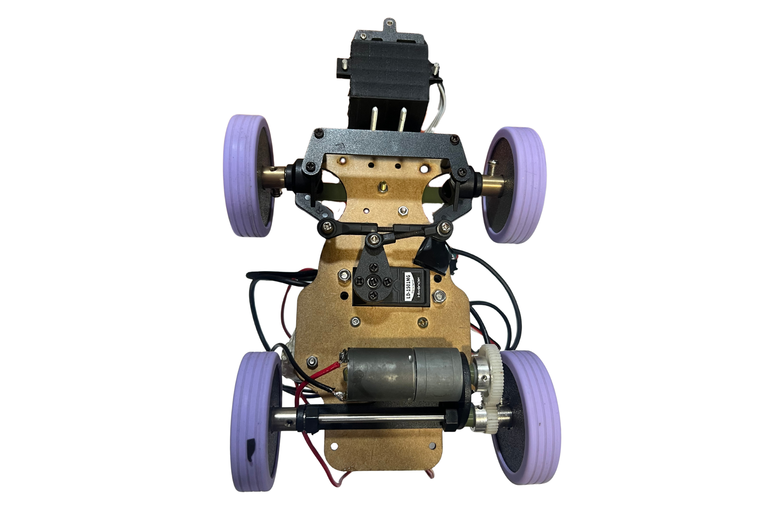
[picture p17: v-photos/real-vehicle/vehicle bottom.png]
|  |  |  |

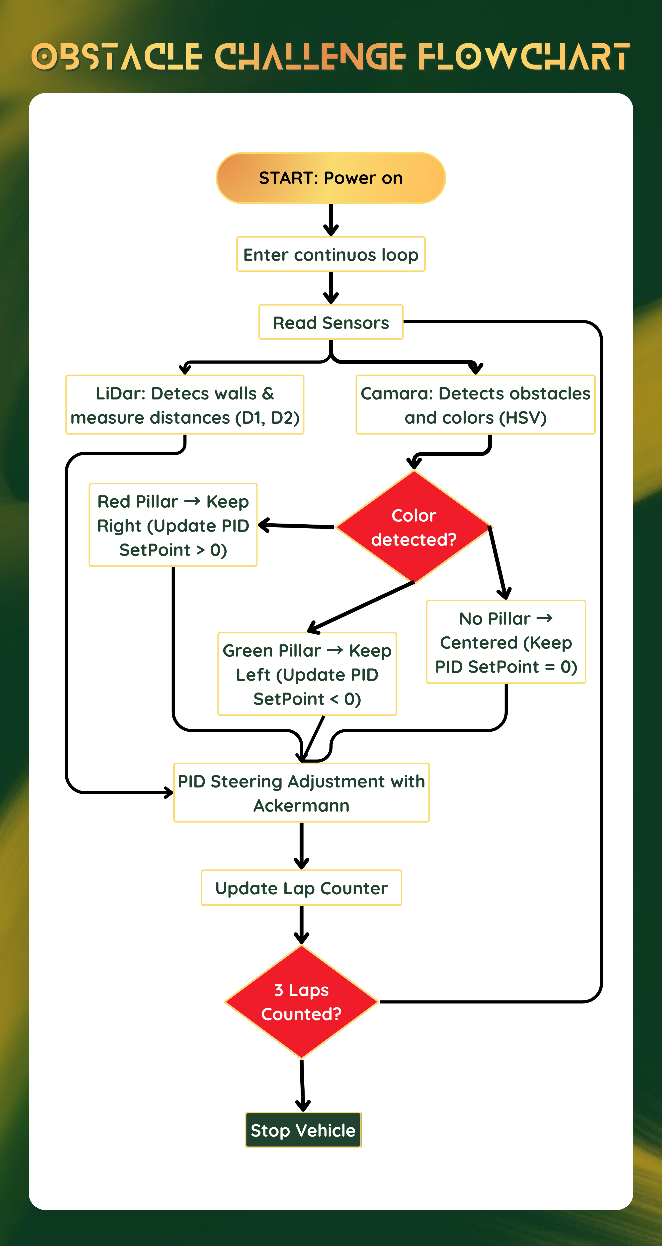
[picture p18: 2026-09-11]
schemes/Obstacle Challenge Flowchart.png

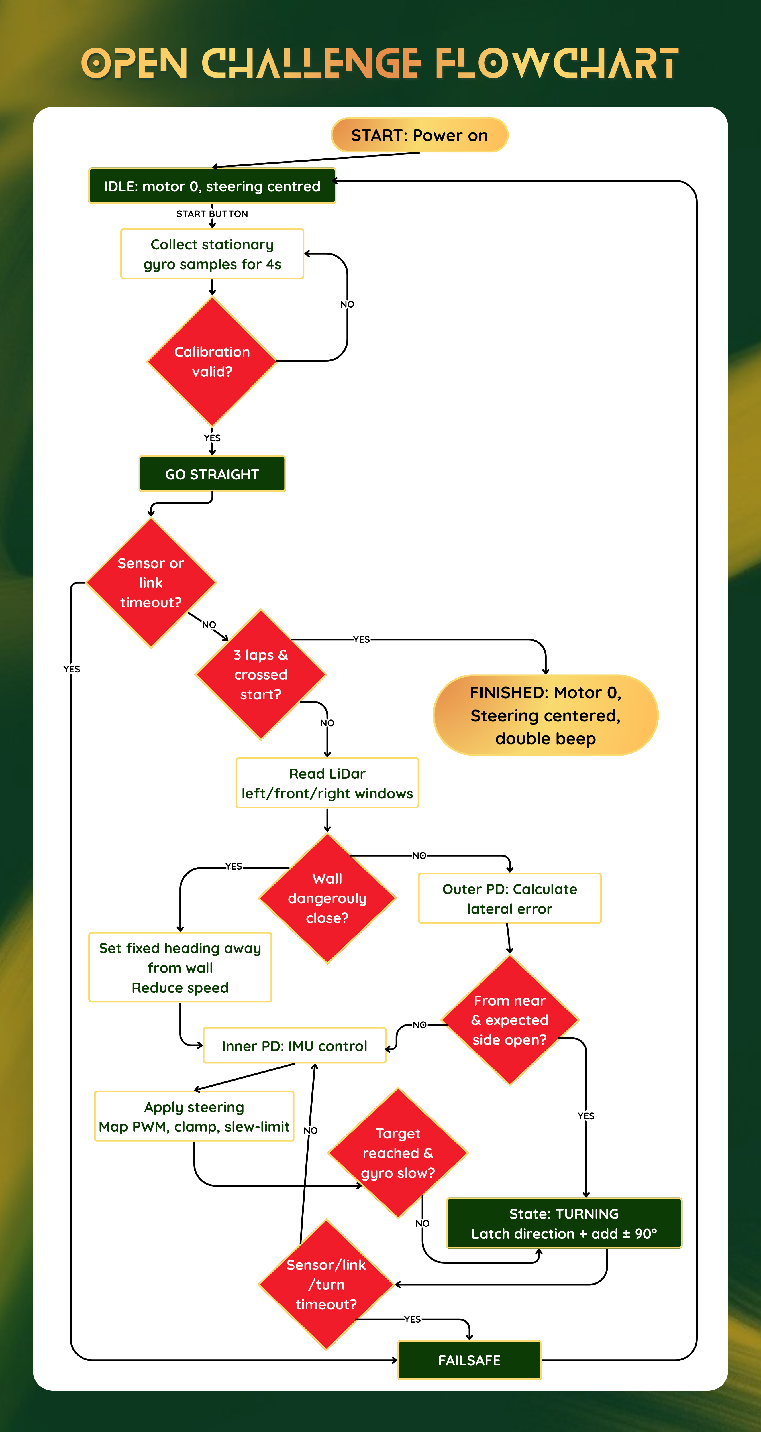
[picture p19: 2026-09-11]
schemes/Open Challenge Flowchart.png

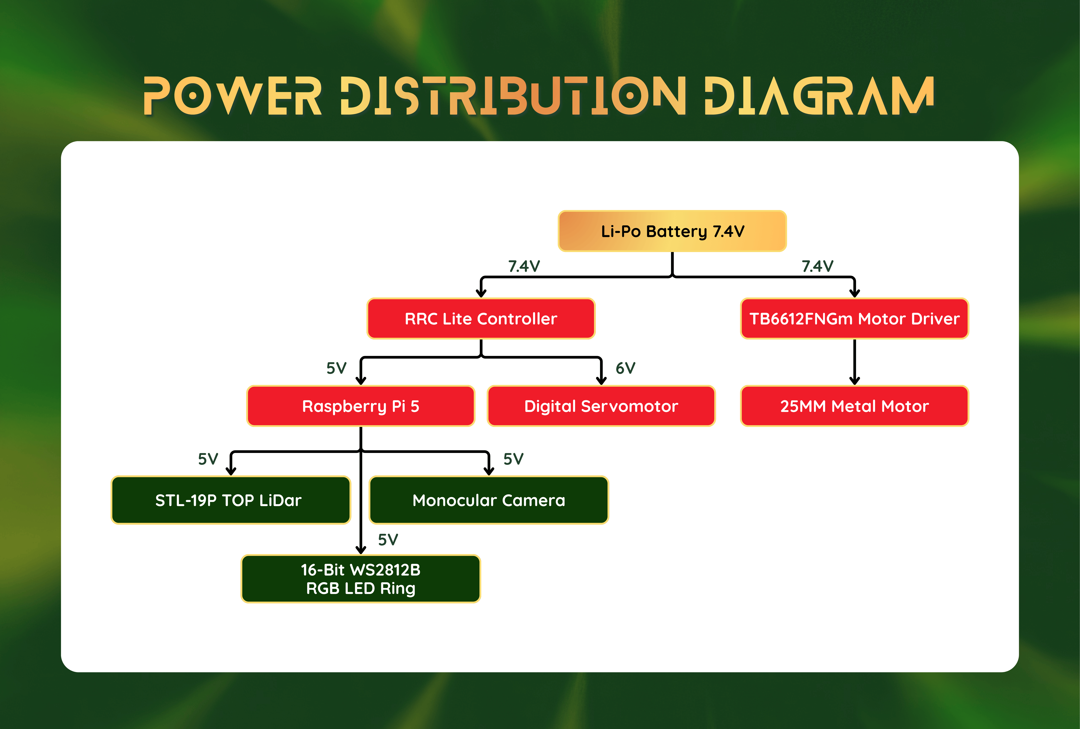
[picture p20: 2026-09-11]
schemes/Power Distribution Diagram.png

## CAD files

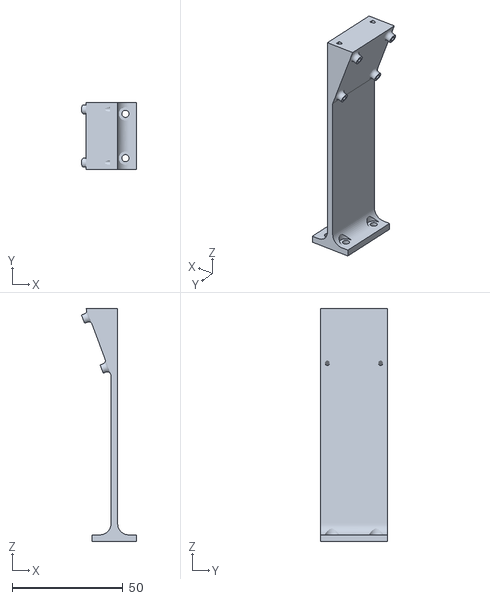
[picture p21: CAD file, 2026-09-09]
models/camara_housing/camara_housing.stl
24.8 x 30.0 x 105.0

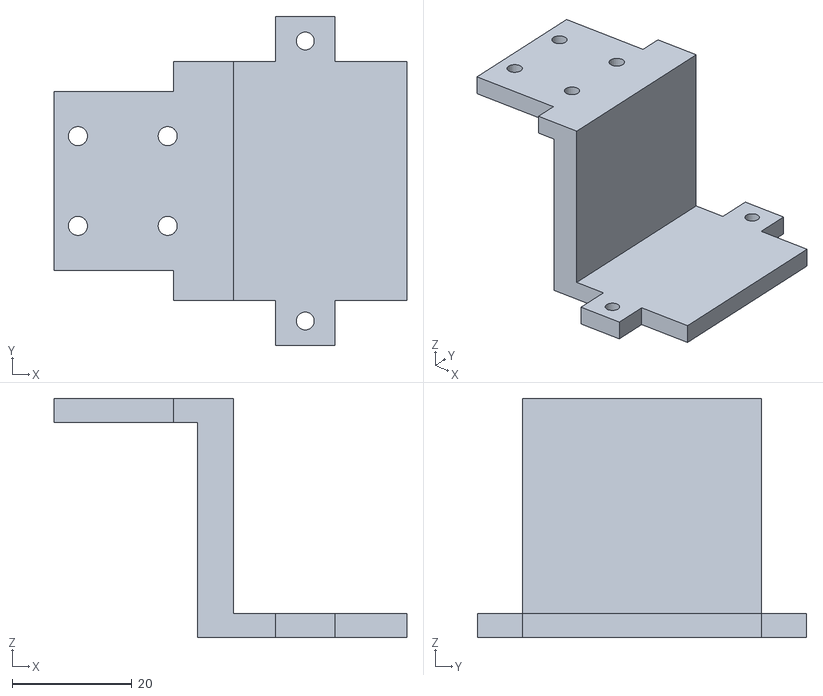
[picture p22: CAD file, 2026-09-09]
models/lidar_housing/lidar_housing.stl
59.0 x 55.0 x 40.0

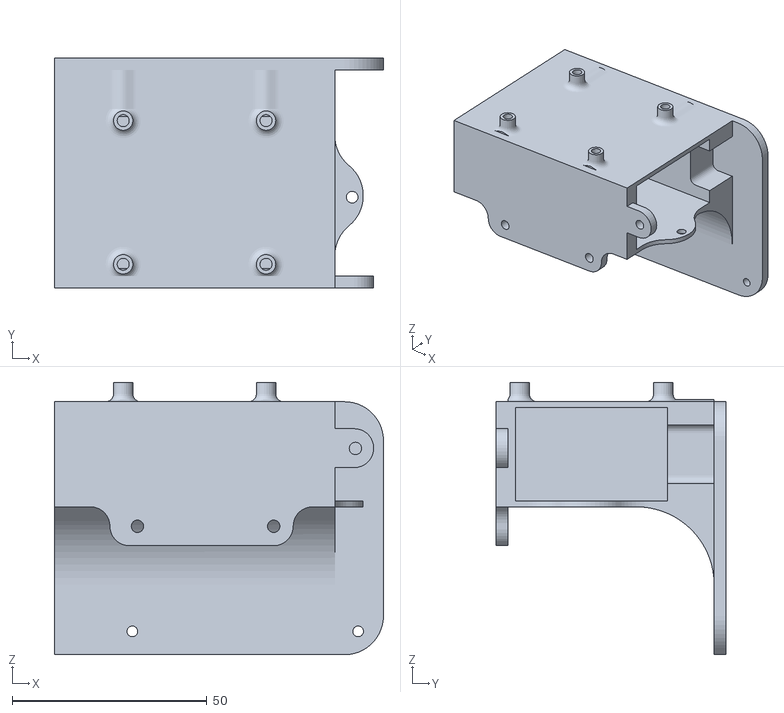
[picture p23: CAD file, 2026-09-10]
models/raspberry_housing/raspberry_housing.stl
84.5 x 59.0 x 70.0

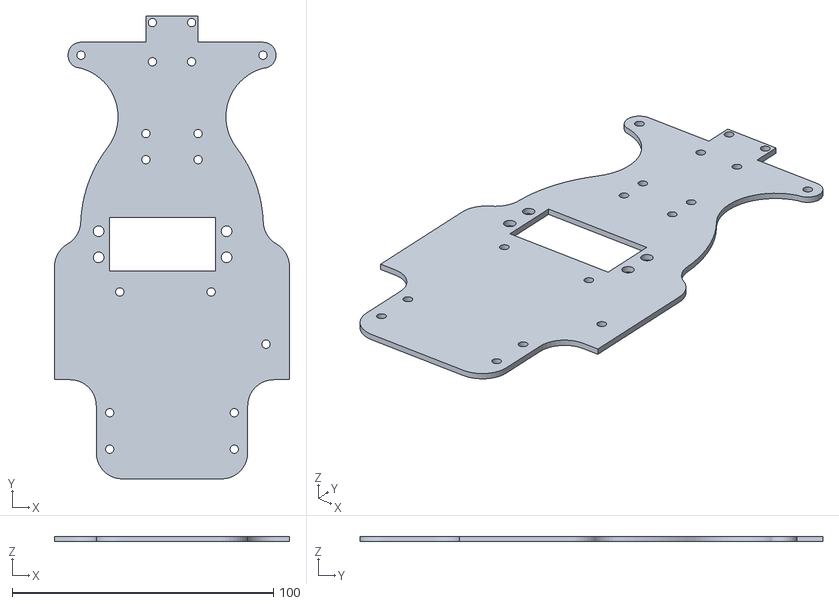
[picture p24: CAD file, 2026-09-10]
models/vehicle_base/vehicle_base.stl
90.0 x 177.3 x 2.00

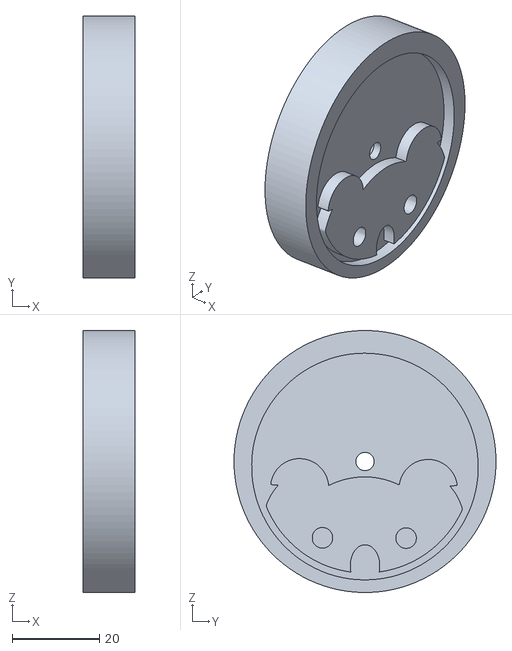
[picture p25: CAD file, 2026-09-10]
models/vehicle_wheels/vehicle_wheels.stl
12.0 x 60.0 x 60.0

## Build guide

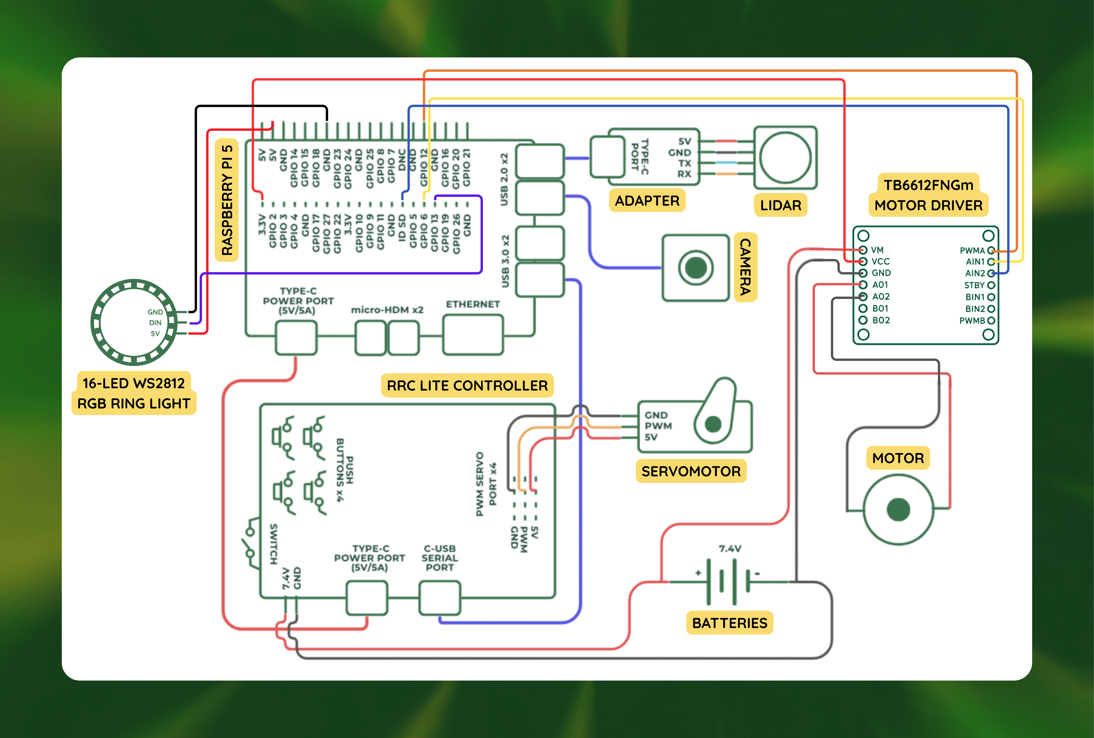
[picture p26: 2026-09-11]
schemes/Electrical Wiring Diagram.png

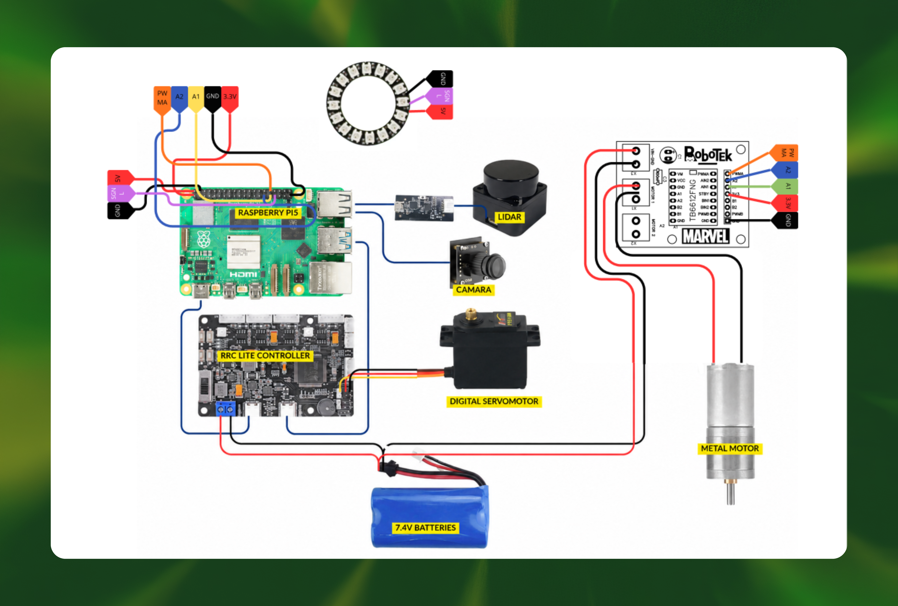
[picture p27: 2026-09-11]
schemes/Visual Wiring Diagram.png

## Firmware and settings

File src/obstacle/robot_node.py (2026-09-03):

#!/usr/bin/env python3
"""Nodo principal del Obstacle Challenge (WRO Future Engineers).

Seguimiento de pared con lazo IMU + vision de color. Maquina de estados:

  IDLE --(boton)--> CALIBRANDO --(4 s)--> SIGUIENDO <--> GIRANDO --(3 vueltas)--> FIN

La camara detecta el bloque mas cercano y elige la pared a seguir (rojo ->
derecha, verde -> izquierda). El lidar da la geometria de la pared y dispara
los giros de esquina. El IMU es el unico lazo que escribe al servo.
"""
import math
import statistics
from enum import Enum, auto

import rclpy
from rclpy.node import Node
from cv_bridge import CvBridge
from sensor_msgs.msg import LaserScan, Imu, Image
from std_msgs.msg import Float32
from ros_robot_controller_msgs.msg import (SetAckerServoState, ButtonState,
                                           BuzzerState)

from config import Config, clamp, wrap180
from color_vision import LIBRE, ROJO, VERDE, detect_block
from control import (InnerLoop, Corner, LapCounter, window_median, delta_to_us,
                     estimate_wall, wall_follow_offset, pillar_nudge_deg,
                     side_for_color, detect_corner, start_turn, turn_complete,
                     turn_timed_out)

BUTTON_MIN_INTERVAL_S = 1.5


class State(Enum):
    IDLE = auto()
    CALIBRANDO = auto()
    SIGUIENDO = auto()
    GIRANDO = auto()
    FIN = auto()


class ObstacleChallenge(Node):
    def __init__(self):
        super().__init__('obstacle_challenge')
        self.cfg = Config()
        self.bridge = CvBridge()

        self.servo_pub = self.create_publisher(
            SetAckerServoState, '/ros_robot_controller/acker_servo/set_state', 10)
        self.motor_pub = self.create_publisher(Float32, '/motor_vel', 10)
        self.buzzer_pub = self.create_publisher(
            BuzzerState, '/ros_robot_controller/set_buzzer', 10)

        self.create_subscription(LaserScan, '/scan', self.scan_callback, 1)
        self.create_subscription(
            Imu, '/ros_robot_controller/imu_raw', self.imu_callback, 1)
        self.create_subscription(
            ButtonState, '/ros_robot_controller/button', self.button_callback, 10)
        self.create_subscription(
            Image, self.cfg.CAMERA_TOPIC, self.camera_callback, 1)

        self.state = State.IDLE
        self.inner = InnerLoop()
        self.corner = Corner()
        self.laps = LapCounter()

        self.wall_side = 'right'
        self.active_color = LIBRE
        self.color_candidate = LIBRE
        self.color_count = 0
        self.block = None

        self.front = self.dL = self.dR = None
        self.theta_ref = 0.0
        self.cal_samples = []
        self.cal_start_t = None
        self.last_imu_t = None
        self.last_scan_t = None
        self.last_button_t = None

        self.create_timer(self.cfg.WATCHDOG_S, self.watchdog_callback)
        self.get_logger().info('Listo. Pulsa el boton para arrancar.')

    # ------------------------------------------------------------------ #
    # utilidades
    # ------------------------------------------------------------------ #
    def now(self):
        return self.get_clock().now().nanoseconds * 1e-9

    def driving(self):
        return self.state in (State.SIGUIENDO, State.GIRANDO)

    def beep(self, freq, dur=0.2, repeat=1):
        msg = BuzzerState()
        msg.freq = int(freq)
        msg.on_time = float(dur)
        msg.off_time = 0.1
        msg.repeat = int(repeat)
        self.buzzer_pub.publish(msg)

    def send_servo(self, us):
        msg = SetAckerServoState()
        msg.position = int(round(clamp(us, self.cfg.SERVO_MIN_US, self.cfg.SERVO_MAX_US)))
        msg.duration = self.cfg.SERVO_CMD_S
        self.servo_pub.publish(msg)

    def send_motor(self, pct):
        self.motor_pub.publish(Float32(data=float(max(0.0, min(100.0, pct)))))

    # ------------------------------------------------------------------ #
    # transiciones de estado
    # ------------------------------------------------------------------ #
    def button_callback(self, msg):
        if msg.state not in (1, 5):
            return
        t = self.now()
        if self.last_button_t is not None and \
                t - self.last_button_t < BUTTON_MIN_INTERVAL_S:
            return
        self.last_button_t = t
        if self.state in (State.IDLE, State.FIN):
            self.start_calibration()
        else:
            self.stop('boton')

    def start_calibration(self):
        self.state = State.CALIBRANDO
        self.cal_samples = []
        self.cal_start_t = self.now()
        self.send_motor(0.0)
        self.send_servo(self.cfg.SERVO_CENTER_US)
        self.get_logger().info('Calibrando giroscopio, mantener el robot quieto...')

    def finish_calibration(self):
        self.inner.bias_deg_s = statistics.fmean(self.cal_samples)
        self.inner.reset(0.0)
        self.corner.reset()
        self.laps.reset()
        self.theta_ref = 0.0
        self.last_imu_t = self.now()
        self.state = State.SIGUIENDO
        self.beep(880, 0.1)
        self.get_logger().info(
            f'Bias gz = {self.inner.bias_deg_s:.3f} deg/s. Arrancando '
            f'(pared {self.wall_side}).')

    def finish(self):
        self.send_motor(0.0)
        self.send_servo(self.cfg.SERVO_CENTER_US)
        self.state = State.FIN
        self.get_logger().info(f'{self.cfg.MAX_LAPS} vueltas completadas.')

    def stop(self, reason):
        self.send_motor(0.0)
        self.send_servo(self.cfg.SERVO_CENTER_US)
        self.corner.turning = False
        self.state = State.IDLE
        self.get_logger().info(f'PARADA ({reason}).')

    # ------------------------------------------------------------------ #
    # camara: color -> pared a seguir
    # ------------------------------------------------------------------ #
    def camera_callback(self, msg):
        try:
            frame = self.bridge.imgmsg_to_cv2(msg, desired_encoding='bgr8')
        except Exception as exc:  # noqa: BLE001
            self.get_logger().warning(f'frame invalido: {exc}')
            return
        self.block = detect_block(frame, self.cfg)
        detected = LIBRE if self.block is None else self.block[0]

        # confirmar el color unos frames antes de fiarse (evita falsos beeps)
        if detected == self.color_candidate:
            self.color_count += 1
        else:
            self.color_candidate = detected
            self.color_count = 1
        if self.color_count < self.cfg.CONFIRM_FRAMES:
            return

        if detected != self.active_color and detected in (ROJO, VERDE):
            self.active_color = detected
            # solo se cambia de pared si aun no se esta girando
            if not self.corner.turning:
                self.wall_side = side_for_color(detected)
            name = 'VERDE -> izquierda' if detected == VERDE else 'ROJO -> derecha'
            self.beep(self.cfg.LAP_BEEP_FREQ, 0.1)
            self.get_logger().info(f'Color {name}.')
        elif detected == LIBRE:
            self.active_color = LIBRE

    # ------------------------------------------------------------------ #
    # lidar: geometria de pared y deteccion de esquina
    # ------------------------------------------------------------------ #
    def scan_callback(self, msg):
        self.last_scan_t = self.now()
        if not self.driving():
            return

        self.front = window_median(msg.ranges, self.cfg.LIDAR_FRONT_DEG, self.cfg)
        self.dL = window_median(msg.ranges, self.cfg.LIDAR_LEFT_DEG, self.cfg)
        self.dR = window_median(msg.ranges, self.cfg.LIDAR_RIGHT_DEG, self.cfg)

        if self.corner.turning:
            return

        theta_rel = wrap180(self.inner.theta_deg - self.corner.heading_base_deg)

        if detect_corner(self.front, self.dL, self.dR, theta_rel,
                         self.corner, self.now(), self.cfg):
            start_turn(self.corner, self.dL, self.dR, self.now(), self.cfg)
            self.theta_ref = 0.0
            lado = 'derecha' if self.corner.direction > 0 else 'izquierda'
            self.get_logger().info(f'Esquina: giro a la {lado}.')
            return

        # rayos de la pared seguida: lateral a 60, adelantado a 30
        if self.wall_side == 'right':
            side_ray = window_median(msg.ranges,
                                     self.cfg.LIDAR_FRONT_DEG - self.cfg.SIDE_RAY_DEG, self.cfg)
            fwd_ray = window_median(msg.ranges,
                                    self.cfg.LIDAR_FRONT_DEG - self.cfg.FORWARD_RAY_DEG, self.cfg)
        else:
            side_ray = window_median(msg.ranges,
                                     self.cfg.LIDAR_FRONT_DEG + self.cfg.SIDE_RAY_DEG, self.cfg)
            fwd_ray = window_median(msg.ranges,
                                    self.cfg.LIDAR_FRONT_DEG + self.cfg.FORWARD_RAY_DEG, self.cfg)

        wall = estimate_wall(side_ray, fwd_ray, self.wall_side, self.cfg)
        offset = wall_follow_offset(wall, self.wall_side, self.cfg)
        offset += pillar_nudge_deg(self.block, self.cfg)
        self.theta_ref = clamp(offset, -self.cfg.FOLLOW_MAX_DEG - self.cfg.PILLAR_MAX_DEG,
                               self.cfg.FOLLOW_MAX_DEG + self.cfg.PILLAR_MAX_DEG)

    # ------------------------------------------------------------------ #
    # imu: rumbo -> servo (unico lazo que manda al servo)
    # ------------------------------------------------------------------ #
    def imu_callback(self, msg):
        gz = getattr(getattr(msg, 'angular_velocity', None), 'z', None)
        if gz is None or not math.isfinite(gz):
            return
        gz_deg = math.degrees(float(gz))
        t = self.now()

        if self.state == State.CALIBRANDO:
            self.cal_samples.append(gz_deg)
            if t - self.cal_start_t >= self.cfg.GYRO_CAL_S:
                self.finish_calibration()
            return

        if not self.driving():
            return

        dt = t - self.last_imu_t if self.last_imu_t is not None else 0.0
        self.last_imu_t = t
        if dt <= 0.0 or dt > self.cfg.IMU_TIMEOUT_S:
            return

        gz_deb = self.inner.integrate(gz_deg, dt, self.cfg)

        if self.laps.update(self.inner.theta_deg, self.cfg):
            self.get_logger().info(f'Vuelta {self.laps.laps}.')
            if self.laps.laps >= self.cfg.MAX_LAPS:
                self.beep(self.cfg.FINISH_BEEP_FREQ, 0.3, repeat=2)
                self.finish()
                return
            self.beep(self.cfg.LAP_BEEP_FREQ, 0.2)

        if self.corner.turning:
            if turn_timed_out(self.corner, t, self.cfg):
                self.stop('timeout de giro')
                return
            if turn_complete(self.corner, self.inner.theta_deg, gz_deb, self.cfg):
                self.corner.turning = False
                self.get_logger().info('Giro completo.')

        if self.corner.turning:
            ref = self.corner.heading_base_deg
        else:
            ref = self.corner.heading_base_deg + self.theta_ref

        delta = self.inner.delta(ref, gz_deb, self.cfg)
        self.send_servo(delta_to_us(delta, self.cfg))

        pct = self.cfg.MOTOR_TURN_PCT if self.corner.turning else self.cfg.MOTOR_CRUISE_PCT
        self.send_motor(pct)

    # ------------------------------------------------------------------ #
    # seguridad
    # ------------------------------------------------------------------ #
    def watchdog_callback(self):
        if not self.driving():
            return
        t = self.now()
        imu_lost = self.last_imu_t and t - self.last_imu_t > self.cfg.IMU_TIMEOUT_S
        scan_lost = self.last_scan_t and t - self.last_scan_t > self.cfg.LIDAR_TIMEOUT_S
        if imu_lost or scan_lost:
            self.send_motor(0.0)
            self.send_servo(self.cfg.SERVO_CENTER_US)


def main(args=None):
    rclpy.init(args=args)
    node = ObstacleChallenge()
    try:
        rclpy.spin(node)
    except KeyboardInterrupt:
        pass
    finally:
        node.send_motor(0.0)
        node.send_servo(node.cfg.SERVO_CENTER_US)
        node.destroy_node()
        rclpy.try_shutdown()


if __name__ == '__main__':
    main()

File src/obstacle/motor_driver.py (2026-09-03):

#!/usr/bin/env python3
"""Driver ROS 2 del TB6612FNG (canal A) para Raspberry Pi 5.

Recibe std_msgs/Float32 en /motor_vel (0..100 %) y mueve el motor hacia
adelante. Al recibir 0 frena brevemente en reversa para quitar la inercia y
despues deja el puente en estado seguro. Un watchdog apaga el motor si dejan
de llegar comandos.
"""
import time

import rclpy
from rclpy.node import Node
from std_msgs.msg import Float32

try:
    import lgpio
except ImportError:
    lgpio = None


class Tb6612Motor(Node):
    def __init__(self):
        super().__init__('tb6612fng_motor')

        self.declare_parameter('gpiochip', 4)
        self.declare_parameter('pwm_a', 12)
        self.declare_parameter('ain1', 5)
        self.declare_parameter('ain2', 6)
        self.declare_parameter('stby', 13)
        self.declare_parameter('pwm_hz', 1000)
        self.declare_parameter('watchdog_s', 0.30)

        self.chip = int(self.get_parameter('gpiochip').value)
        self.pins = {name: int(self.get_parameter(name).value)
                     for name in ('pwm_a', 'ain1', 'ain2', 'stby')}
        self.hz = int(self.get_parameter('pwm_hz').value)
        self.watchdog_s = float(self.get_parameter('watchdog_s').value)

        self.gpio = None
        self.last_command = time.monotonic()
        self.last_pct = 0.0
        self.braking_until = None

        if lgpio is None:
            self.get_logger().error('Falta lgpio; motor deshabilitado.')
        else:
            self.gpio = lgpio.gpiochip_open(self.chip)
            for pin in self.pins.values():
                lgpio.gpio_claim_output(self.gpio, pin, 0)
            self.stop_motor()
            self.get_logger().info('TB6612FNG listo.')

        self.create_subscription(Float32, '/motor_vel', self.on_command, 10)
        self.create_timer(0.05, self.on_watchdog)

    def stop_motor(self):
        if self.gpio is None:
            return
        lgpio.tx_pwm(self.gpio, self.pins['pwm_a'], self.hz, 0)
        for name in ('ain1', 'ain2', 'stby'):
            lgpio.gpio_write(self.gpio, self.pins[name], 0)
        self.last_pct = 0.0
        self.braking_until = None

    def drive(self, pct):
        lgpio.gpio_write(self.gpio, self.pins['ain1'], 1)
        lgpio.gpio_write(self.gpio, self.pins['ain2'], 0)
        lgpio.gpio_write(self.gpio, self.pins['stby'], 1)
        if pct >= 100.0:
            lgpio.gpio_write(self.gpio, self.pins['pwm_a'], 1)
        else:
            lgpio.tx_pwm(self.gpio, self.pins['pwm_a'], self.hz, pct)
        self.last_pct = pct

    def brake(self):
        """Invierte el motor un instante para frenar la inercia."""
        pct = self.last_pct
        lgpio.gpio_write(self.gpio, self.pins['ain1'], 0)
        lgpio.gpio_write(self.gpio, self.pins['ain2'], 1)
        lgpio.gpio_write(self.gpio, self.pins['stby'], 1)
        lgpio.tx_pwm(self.gpio, self.pins['pwm_a'], self.hz, pct)
        self.braking_until = time.monotonic() + 0.12
        self.last_pct = 0.0

    def on_command(self, msg):
        try:
            pct = float(msg.data)
        except (TypeError, ValueError):
            pct = 0.0
        pct = max(0.0, min(100.0, pct))
        self.last_command = time.monotonic()
        if self.gpio is None:
            return
        if pct <= 0.0:
            if self.braking_until is None and self.last_pct > 0.0:
                self.brake()
            elif self.braking_until is None:
                self.stop_motor()
            return
        self.braking_until = None
        self.drive(pct)

    def on_watchdog(self):
        if self.braking_until is not None:
            if time.monotonic() >= self.braking_until:
                self.stop_motor()
            return
        if time.monotonic() - self.last_command > self.watchdog_s:
            self.stop_motor()

    def destroy_node(self):
        self.stop_motor()
        if self.gpio is not None:
            lgpio.gpiochip_close(self.gpio)
            self.gpio = None
        super().destroy_node()


def main(args=None):
    rclpy.init(args=args)
    node = Tb6612Motor()
    try:
        rclpy.spin(node)
    except KeyboardInterrupt:
        pass
    finally:
        node.destroy_node()
        rclpy.try_shutdown()


if __name__ == '__main__':
    main()
